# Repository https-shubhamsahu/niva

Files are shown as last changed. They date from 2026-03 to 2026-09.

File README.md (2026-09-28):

# Niva

**Every step, understood.**

Niva is an explainable gait-analytics platform for a smart insole. Plantar pressure, impact, and IMU telemetry are acquired on an ESP32, streamed to software, then scored with explicit biomechanics rules rather than a black-box model.

This repository is a monorepo for the three implemented Niva applications.

## Architecture

```text
Smart Insole (FSR + piezo + MPU6050)
    ↓
ESP32 firmware  (niva arduino)
    ↓
BLE is not implemented. Live transport is USB Serial and Wi-Fi WebSocket.
    ↓
Web dashboard / optional WS relay  (niva web)
    ↓
Clinician / analytics UI

Flutter app  (niva flutter)
    ↓
Patient/user-facing mobile experience (same JSON telemetry protocol)
```

What is actually in the code:

- Firmware reads four FSR channels, a piezoelectric channel, and an MPU6050 IMU (in the active sketch).
- Telemetry is JSON over WebSocket (`:81`) and CSV over USB Serial at 115200 baud.
- The web app is a React + Vite clinician/research dashboard with IndexedDB storage.
- The Flutter app is a native rebuild of that dashboard for mobile, using Hive instead of IndexedDB.
- EMA filtering and gait-phase logic live in the software biomechanics engines, not as a separate firmware filter stage.
- The implemented IMU is **MPU6050**. This repo does not contain BMI270 firmware.

## Repository structure

```text
Niva/
├── niva flutter/     Mobile application (Flutter)
├── niva arduino/     ESP32 / Arduino firmware
├── niva web/         Clinician dashboard, Vite app, and WS relay
├── hardware/         Wearable hardware prototype: CAD, KiCad, renders (engineering prototype)
├── docs/brand/       Logo source assets
├── README.md
└── .github/          GitHub Pages deploy workflow
```

| Directory | Responsibility |
|---|---|
| `niva flutter/` | Patient/user-facing Flutter app: dashboard, device pairing over WebSocket, insights, trends, CSV export |
| `niva arduino/` | ESP32 firmware: ADC acquisition, calibration, IMU, telemetry, Wi-Fi / WebSocket |
| `niva web/` | Clinician dashboard, biomechanics visualization, dataset export/upload, optional WebSocket relay |
| `hardware/` | Rev C.1 wearable prototype: printable FreeCAD pod enclosure and charging dock; KiCad 9 pod (routed, DRC-clean), cartridge strip, dock and insole sensing flex; verification plan; Blender scenes. Start at `hardware/outputs/NIVA-3D-engineering-prototype/README.md`. Not reviewed or released for fabrication. |

## Development prerequisites

Install only what you need for the component you are running:

- **Web:** Node.js 22+ and npm
- **Flutter:** Flutter SDK (Dart 3.3+)
- **Firmware:** Arduino IDE (or compatible ESP32 toolchain) with ESP32 board support

## How to run each component

### Web dashboard (`niva web`)

```bash
cd "niva web"
npm install
# if peer dependency conflicts appear:
npm install --legacy-peer-deps
npm run dev
```

Other supported scripts:

```bash
npm run build
npm run preview
npm run lint
```

Optional environment file: create `niva web/.env.local`

```bash
VITE_ESP32_WS_URL=ws://<esp32-ip>:81
VITE_ESP32_WS_RELAY_URL=wss://<your-relay-domain>/ws
VITE_ESP32_WS_RELAY_TARGET_KEY=target
VITE_DATASET_UPLOAD_URL=https://your-api.example.com/upload
VITE_DATASET_UPLOAD_TOKEN=your_optional_bearer_token
```

Optional local WebSocket relay (needed when a HTTPS dashboard must reach a `ws://` ESP32):

```bash
cd "niva web/relay"
npm install
npm start
```

### Flutter app (`niva flutter`)

```bash
cd "niva flutter"
flutter pub get
flutter analyze
flutter test
flutter run
```

ESP32 endpoint, relay URL, and upload URL are runtime settings on the Device tab (not build-time env files).

### Firmware (`niva arduino`)

Open one of these sketches in Arduino IDE, install the libraries listed in `niva arduino/README.md`, select an ESP32 board, and upload:

- **Active hardware sketch:** `niva arduino/niva_hardware/niva_hardware.ino`
- **Simpler hardcoded-WiFi sketch:** `niva arduino/esp32_gaitguard_wifi_manager/esp32_gaitguard_wifi_manager.ino`

Serial Monitor baud rate: **115200**.

## Hardware / firmware overview

Implemented on ESP32:

- FSR heel / inner / outer / toe on ADC pins 32, 33, 34, 35
- Piezoelectric heel disc on pin 36
- MPU6050 on I2C (SDA 21, SCL 22) in the active `niva_hardware` sketch
- Optional SH1106 OLED on the same I2C bus (address 0x3C)
- Oversampled ADC reads and zero-load tare calibration (NVS-persisted in the active sketch)
- WebSocket telemetry on port 81, USB CSV telemetry on Serial

The simpler `esp32_gaitguard_wifi_manager` sketch uses hardcoded Wi-Fi credentials and does not drive the IMU or OLED.

## Software overview

- **Web:** React 19, TypeScript, Vite, Tailwind, Recharts, IndexedDB
- **Flutter:** Flutter, Riverpod, Hive, `web_socket_channel`, `fl_chart`
- **Relay:** Node.js + `ws`
- **Deploy:** GitHub Pages via `.github/workflows/deploy-pages.yml` (builds `niva web`)

There is no application server or database in this repository. Dataset persistence is browser-local (IndexedDB) or on-device (Hive). CSV upload to an external research API is optional.

## Documentation

| Location | Contents |
|---|---|
| `niva flutter/README.md` | Flutter setup, architecture, and run commands |
| `niva arduino/README.md` | Firmware sketches, pin map, libraries |
| `niva web/README.md` | Dashboard setup, telemetry formats, Pages deploy |
| `niva web/JUDGES_WALKTHROUGH.md` | Algorithm and data walkthrough |
| `niva flutter/DESIGN.md` | Flutter visual/design notes |
| `niva flutter/BACKEND_LOGIC.md` | Data contract and storage |
| `docs/brand/` | Logo source assets |

This prototype is an engineering / research screening tool. It is not a medical diagnosis device.

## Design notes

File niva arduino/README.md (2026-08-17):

# Niva Arduino / ESP32 firmware

Embedded firmware for the Niva smart insole. This directory contains the ESP32 sketches that acquire FSR, piezo, and IMU data and stream telemetry to the Flutter app and web dashboard.

## Technology stack

- ESP32 + Arduino core
- WebSockets (Markus Sattler)
- WiFiManager (tzapu) in the active sketch
- U8g2 (olikraus) for the SH1106 OLED in the active sketch
- MPU6050 over raw I2C (address `0x68`) in the active sketch

There is no PlatformIO `platformio.ini` in this repository. Flash with Arduino IDE (or another Arduino-compatible ESP32 toolchain).

## Sketches

### Active: `niva_hardware/niva_hardware.ino`

This is the complete hardware sketch currently used on the insole:

- WiFiManager captive portal (`NIVA-GaitGuard-AP`)
- MPU6050 pitch / roll / accZ
- SH1106 128x64 OLED status display on the shared I2C bus
- 16x ADC oversampling
- Zero-load tare calibration with NVS persistence
- mDNS names `niva.local` / `gaitguard.local`
- WebSocket JSON on port 81 and USB CSV on Serial

Required libraries:

- WiFiManager by tzapu
- WebSockets by Markus Sattler
- U8g2 by olikraus

### Simpler variant: `esp32_gaitguard_wifi_manager/esp32_gaitguard_wifi_manager.ino`

Earlier GitHub sketch kept because it is still a valid, smaller firmware:

- Hardcoded SSID / password (`YOUR_HOTSPOT_NAME` / `YOUR_HOTSPOT_PASSWORD`)
- Zero-load calibration (40 samples, not stored in NVS)
- WebSocket JSON + USB CSV
- `pitch` / `roll` / `accZ` are sent as `0.0` (no IMU)

Required libraries:

- WebSockets by Markus Sattler

## Pin map (both sketches)

| Signal | GPIO |
|---|---|
| FSR heel | 32 |
| FSR inner | 33 |
| FSR outer | 34 |
| FSR toe | 35 |
| Piezo | 36 |
| I2C SDA (MPU6050 + OLED) | 21 |
| I2C SCL | 22 |
| Status LED | 2 |

## Telemetry

JSON over WebSocket (`ws://<esp32-ip>:81`):

```json
{"heel":42.00,"inner":68.00,"outer":31.00,"toe":27.00,"piezo":176.00,"pitch":-2.40,"roll":1.30,"accZ":9.72}
```

USB Serial CSV at 115200 baud:

```text
H,I,O,T,Piezo,Pitch,Roll,AccZ
```

Gait-phase classification and EMA smoothing are applied in `niva web` and `niva flutter`, not in these sketches.

## Setup / flash

1. Install Arduino IDE and ESP32 board support.
2. Install the libraries listed for the sketch you are flashing.
3. For the simpler sketch, edit `WIFI_SSID` and `WIFI_PASS` before upload.
4. Select your ESP32 board and port.
5. Open the `.ino` and upload.
6. Open Serial Monitor at **115200** baud and note the printed IP address.
7. Point the Flutter Device tab or the web Settings page at `ws://<ESP32_IP>:81`.

Runtime tare on the active sketch: send `calibrate` or `tare` over WebSocket or Serial.

## Connection to other Niva components

- `niva flutter` connects over WebSocket using the same JSON packet.
- `niva web` connects over WebSocket or USB Web Serial using the same JSON/CSV packet.
- `niva web/relay` can bridge `wss://` (HTTPS GitHub Pages) to the ESP32 `ws://` endpoint.

## Implementation notes

- IMU in firmware is **MPU6050**, not BMI270.
- Production ideas such as ESP32-C3, FPC insole, or screen-printed layers are not implemented in these sketches.
- BLE is not implemented in firmware.

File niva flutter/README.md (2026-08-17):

# Niva Flutter

Patient/user-facing mobile application for Niva (GaitGuard Nexus). This is a native Flutter rebuild of the web dashboard: Apple Health-inspired cards and activity rings, a procedurally drawn plantar pressure map, and the same explainable biomechanics engine.

It is not a WebView wrapper. It speaks the same ESP32 JSON-over-WebSocket protocol as `niva web`.

## Technology stack

- Flutter / Dart 3.3+
- Riverpod
- Hive + `shared_preferences`
- `web_socket_channel`
- `fl_chart`, `google_fonts`, `share_plus`, `http`

Platform folders already in this project: `android/`, `ios/`, `windows/`, `web/`.

## Directory structure

```text
lib/
  core/
    models/            Packet and metric types
    engine/            BiomechanicsEngine + SimulationEngine
    connectivity/      Esp32SocketService (WebSocket + reconnect)
    data/              Hive dataset store, settings, optional CSV upload
    providers/         TelemetryController is the source of truth
  features/
    dashboard/         Today: rings, foot map, live metrics
    trends/            Cadence / stability / impact charts
    insights/          Clinical summary + AI coach card
    device/            Connection, session metadata, export/upload
    shell/             Bottom tab shell
  theme/
  shared/widgets/
test/
  biomechanics_engine_test.dart
assets/
  images/feet.png
  icon/
```

## Setup

```bash
cd "niva flutter"
flutter pub get
flutter analyze
flutter test
flutter run
```

Android already enables `INTERNET` and `usesCleartextTraffic` so `ws://` ESP32 endpoints on the LAN can connect. iOS still needs a local-network usage description if you ship to a device (see `ios/Runner/Info.plist`).

## Configuration

There is no `.env` file. WebSocket URL, optional relay URL, session/trial IDs, and upload endpoint are runtime settings on the Device tab, persisted with `shared_preferences`.

## Connection to other Niva components

- Firmware: `niva arduino/niva_hardware/niva_hardware.ino` (active) or the simpler `esp32_gaitguard_wifi_manager` sketch. Packet shape is the same.
- Web: `niva web` is the clinician dashboard with USB Serial plus extra visualization pages that were not ported here (3D foot views, clinician PDF).
- BLE / USB-OTG are not implemented in this app. See `BETTERMENTS.md` and `CONNECTIVITY_PLAN.md`.

## Additional docs in this folder

- `DESIGN.md` — visual language
- `BACKEND_LOGIC.md` — data contract and storage
- `SIMULATION_LOGIC.md` — disease-mode simulator
- `BETTERMENTS.md` — follow-up ideas (BLE, HealthKit, etc.)

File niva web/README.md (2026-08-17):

# Niva web

Clinician / research dashboard for Niva (GaitGuard Nexus): live ESP32 telemetry, explainable gait analytics, IndexedDB datasets, and GitHub Pages deployment. The optional WebSocket relay lives in `relay/`.

# GaitGuard Nexus (NIVA)

<p align="center">
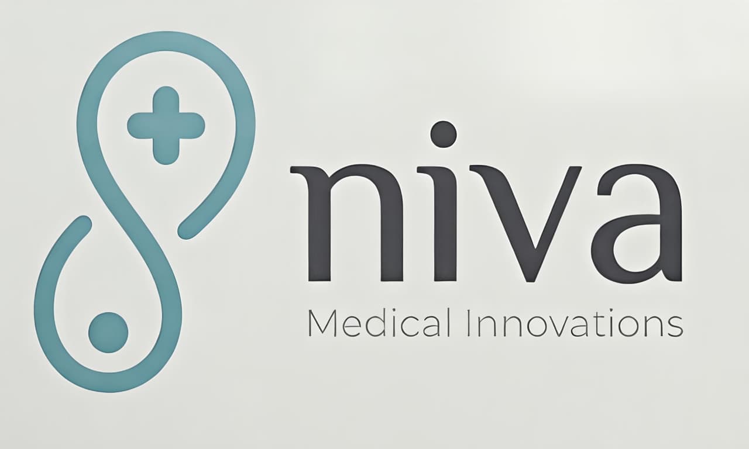
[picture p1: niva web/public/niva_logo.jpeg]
NIVA Logo
  
</p>

<p align="center">
  
  
  
  
</p>

Deterministic, explainable gait analytics platform for ESP32 smart insole telemetry.

This project focuses on transparent biomechanics logic rather than black-box prediction. Every score and alert can be traced to explicit sensor rules.

## Tech Stack

| Layer | Technology |
|---|---|
| Frontend | React, TypeScript, Vite |
| Hardware link | Web Serial (USB) + WebSocket (WiFi) |
| Storage | IndexedDB (browser-local dataset store) |
| Firmware | ESP32 (Arduino, WiFiManager + WebSockets) |
| Deployment | GitHub Pages via GitHub Actions |

## What This Project Does

- Streams plantar + IMU telemetry from ESP32 over USB Serial and WiFi WebSocket.
- Runs a real-time biomechanics engine for gait phase, cadence, COP, stability, and anomaly detection.
- Stores samples locally in IndexedDB with disease/session/trial metadata.
- Exports datasets as CSV and supports one-click backend upload for research pipelines.
- Supports disease-mode simulation for demos and algorithm walkthroughs.

## Explainability First

This is an explainable rule-based system. Core decisions are derived from explicit thresholds and state transitions:

- Contact detection from total normalized plantar pressure.
- Heel-strike events from impact + heel-rise transition constraints.
- Gait phase classification using interpretable phase rules.
- Cadence from heel-strike intervals.
- Stability from pitch/roll sway and impact penalties.
- Risk flags from sustained pressure and kinematic instability conditions.

Primary implementation file:

- src/utils/biomechanicsEngine.ts

## Data Pipeline

End-to-end flow:

ESP32 packet -> transport parsing -> biomechanics engine -> dashboard state -> dataset store -> CSV/export/upload

Coordinator file:

- src/pages/MainDashboard.tsx

## Architecture Diagram

<p align="center">
  GaitGuard Nexus Architecture Diagram
</p>

## Supported Input Formats

### USB Serial (CSV)

Expected line format:

```text
H,I,O,T,Piezo,Pitch,Roll,AccZ
```

Example:

```text
45,70,25,20,160,-2.1,1.4,9.78
```

### WiFi WebSocket (JSON)

Example payload:

```json
{"heel":42,"inner":68,"outer":31,"toe":27,"pitch":-2.4,"roll":1.3,"piezo":176,"accZ":9.72}
```

## Dataset Schema

Samples are persisted in browser IndexedDB.

- Database: gaitguard-nexus-datasets
- Store: esp32_samples

Per sample fields:

- timestampMs
- source (usb | ws | sim)
- sessionId
- trialId
- diseaseLabel (Unknown | Normal | Parkinson | Stroke | Neuropathy | Foot Drop | Ataxia)
- mode (live | simulation)
- heel
- inner
- outer
- toe
- impact
- pitch
- roll
- accZ

Disease labeling behavior:

- Live USB/WiFi packets use operator-selected disease label.
- Simulation packets auto-tag from active simulation mode.

## Backend Upload Contract

One-click upload sends multipart form-data with:

- file (CSV)
- sampleCount
- generatedAt
- datasetType (esp32-biomechanics)
- sessionId
- trialId
- diseaseLabel

Upload helper:

- src/utils/researchUpload.ts

## Quick Start

1. Install dependencies:

```bash
npm install
```

2. If peer dependency conflicts appear, use:

```bash
npm install --legacy-peer-deps
```

3. Start development server:

```bash
npm run dev
```

4. Open the app URL shown by Vite.

## Environment Variables

Create `.env.local` in this `niva web` directory if needed:

```bash
VITE_ESP32_WS_URL=ws://<esp32-ip>:81
VITE_ESP32_WS_RELAY_URL=wss://<your-relay-domain>/ws
VITE_ESP32_WS_RELAY_TARGET_KEY=target
VITE_DATASET_UPLOAD_URL=https://your-api.example.com/upload
VITE_DATASET_UPLOAD_TOKEN=your_optional_bearer_token
```

## ESP32 on Any Device (WiFi and Hotspot)

Use Settings -> ESP32 WebSocket Raw Stream to set endpoint at runtime.

Examples:

- `ws://192.168.4.1:81` (ESP32 AP mode)
- `ws://<hotspot-assigned-esp32-ip>:81`
- `wss://<your-secure-relay-domain>/ws` (recommended for deployed HTTPS pages)

Important browser rule:

- GitHub Pages runs on HTTPS.
- Browsers block `ws://` from HTTPS pages (mixed-content restriction).
- For deployed usage on any device, configure `VITE_ESP32_WS_RELAY_URL` (wss) so the app automatically switches to relay mode.
- If relay is not configured, open the app locally over HTTP for direct `ws://` testing.

Automatic seamless fallback:

- App attempts direct mode when allowed.
- On HTTPS + `ws://` endpoint, app auto-routes through relay when `VITE_ESP32_WS_RELAY_URL` is set.
- Relay query parameter name defaults to `target`, configurable via `VITE_ESP32_WS_RELAY_TARGET_KEY`.

Sharing endpoint to another device:

- Use `Copy Share Link` in Settings.
- The generated URL includes `?esp32ws=<endpoint>` and auto-applies endpoint on open.

## Beginner WiFi Setup for ESP32

This section is for first-time users with no networking background.

Ready-to-flash firmware lives in `niva arduino/`:

- Active hardware sketch: `niva arduino/niva_hardware/niva_hardware.ino` (WiFiManager, MPU6050, OLED)
- Simpler hardcoded-WiFi sketch: `niva arduino/esp32_gaitguard_wifi_manager/esp32_gaitguard_wifi_manager.ino`

See `niva arduino/README.md` for libraries and pin map.

### What you are configuring

Your ESP32 needs to do two things:

1. Join a WiFi network (home WiFi or phone hotspot).
2. Expose a WebSocket stream so the dashboard can read live packets.

### Method 1: Hardcode hotspot or WiFi in firmware (easiest)

Use this when starting out.

```cpp
#include <WiFi.h>
#include <WebSocketsServer.h>

const char* ssid = "ShubhamHotspot";
const char* password = "12345678";

WebSocketsServer wsServer(81);

void setup() {
  Serial.begin(115200);

  WiFi.begin(ssid, password);
  Serial.print("Connecting to WiFi");
  while (WiFi.status() != WL_CONNECTED) {
    delay(500);
    Serial.print('.');
  }

  Serial.println("\nWiFi Connected");
  Serial.print("ESP32 IP: ");
  Serial.println(WiFi.localIP());

  wsServer.begin();
}

void loop() {
  wsServer.loop();

  const String packet =
    "{\"heel\":0,\"inner\":0,\"outer\":0,\"toe\":0,\"pitch\":0,\"roll\":0,\"piezo\":0,\"accZ\":0}";

  wsServer.broadcastTXT(packet);
  delay(100);
}
```

After upload, open Serial Monitor. You should see:

- `WiFi Connected`
- `ESP32 IP: 10.x.x.x` or `192.168.x.x`

Then in app Settings:

- Connection Endpoint: `ws://<ESP32_IP>:81/`

If using deployed HTTPS app, also set Relay Endpoint.

### Method 2: WiFiManager (pro move)

If you do not want to hardcode WiFi every time:

- ESP32 creates its own setup WiFi.
- You connect once, enter credentials, and ESP32 saves them.

```cpp
#include <WiFi.h>
#include <WiFiManager.h>

WiFiManager wm;

void setup() {
  Serial.begin(115200);

  bool connected = wm.autoConnect("ESP32_Setup");
  if (!connected) {
    Serial.println("Failed to connect");
    return;
  }

  Serial.println("WiFi Connected");
  Serial.print("ESP32 IP: ");
  Serial.println(WiFi.localIP());
}

void loop() {}
```

How it works:

1. ESP32 starts temporary AP: `ESP32_Setup`.
2. Connect your phone to it.
3. Open `192.168.4.1` in browser.
4. Enter hotspot SSID/password.
5. ESP32 saves and reconnects automatically next boot.

### Common mistakes (do not ignore)

- Wrong hotspot name/password.
- WiFi names are case-sensitive (`ShubhamHotspot` is not `shubhamhotspot`).
- Weak hotspot signal (keep phone close to ESP32).
- 5 GHz hotspot only (ESP32 needs 2.4 GHz).
- Forgot to reboot ESP32 after changing WiFi.

### Pro tips

- Always print IP after connect:

```cpp
Serial.println(WiFi.localIP());
```

- Add LED indicator for connected/disconnected state.
- Use WiFiManager for real deployments with changing hotspots.
- Add auto-reconnect logic in `loop()`.

### Reality check

ESP32 does not behave like a phone that auto-discovers everything.

You must provide:

- WiFi network name
- WiFi password

Or implement logic (WiFiManager/fallback) that collects and stores this for you.

### Switching to another phone hotspot

When you change hotspot, ESP32 usually gets a new IP.

Do this every time:

1. Connect ESP32 and your relay laptop to the new hotspot.
2. Reboot ESP32.
3. Read new IP from Serial Monitor.
4. Update app Connection Endpoint to `ws://<new_ip>:81/`.
5. Keep same relay URL if still active, otherwise generate a new tunnel URL.

### Connection pitfalls in this project

- Relay URL expired (quick tunnel links are temporary).
- ESP32 got a new hotspot IP and app still points to old IP.

### Make it less fragile (recommended)

For better real-world behavior, implement:

- Auto reconnect when `WiFi.status() != WL_CONNECTED`.
- Fallback list of known SSIDs.
- Periodic `Serial.println(WiFi.localIP())` after reconnect.
- Status LED for connected/disconnected state.

## Main Routes

- /main: live telemetry dashboard + simulation + dataset controls
- /settings: Nexus console, hardware matrix, raw WebSocket monitor
- /insights: clinical insights views
- /trends: trend analytics

Router definition:

- src/App.tsx

## Key Files

- src/pages/MainDashboard.tsx: transport integration, engine binding, dataset actions
- src/utils/biomechanicsEngine.ts: explainable gait algorithms
- src/utils/esp32Telemetry.ts: USB CSV parser
- src/hooks/useSensorData.ts: WebSocket hook with reconnect
- src/utils/telemetryDatasetStore.ts: IndexedDB and CSV export
- src/utils/researchUpload.ts: backend upload utility
- src/utils/simulationEngine.ts: synthetic disease-mode frame generator
- JUDGES_WALKTHROUGH.md: algorithm and data presentation script

## Scripts

- npm run dev: start local dev server
- npm run build: type-check and production build
- npm run preview: preview production build
- npm run lint: run ESLint

## WebSocket relay

`relay/` is a small Node.js proxy used when a HTTPS dashboard (GitHub Pages) must reach an ESP32 `ws://` endpoint.

```bash
cd relay
npm install
npm start
```

Default listen URL: `http://localhost:8787` with WebSocket path `/ws`. Do not commit `node_modules` or cloudflared log files.

## Deploy to GitHub Pages

This repo is configured for Pages deployment through GitHub Actions.

Workflow file (repository root):

- `.github/workflows/deploy-pages.yml` (builds this `niva web` directory)

How it works:

1. On push to main (or manual run), GitHub Actions installs dependencies and builds the Vite app.
2. Build base path is set automatically to /<repo>/ in CI using GITHUB_REPOSITORY.
3. The workflow copies dist/index.html to dist/404.html for SPA route fallback.
4. The generated dist artifact is deployed to GitHub Pages.

One-time GitHub setup:

1. Open repository Settings -> Pages.
2. Under Build and deployment, set Source to GitHub Actions.
3. Push your latest code to main.
4. Wait for Deploy to GitHub Pages workflow to complete.

Expected URL format:

- https://<your-username>.github.io/<your-repo>/

### Configure Relay Variables for Pages Build

For seamless ESP32 connectivity on deployed HTTPS pages, set repository variables:

1. Open GitHub repository Settings -> Secrets and variables -> Actions -> Variables.
2. Add variable VITE_ESP32_WS_RELAY_URL with your secure relay endpoint (example: wss://relay.yourdomain.com/ws).
3. Optional: add variable VITE_ESP32_WS_RELAY_TARGET_KEY if your relay expects a key other than target.
4. Optional: add variable VITE_ESP32_WS_URL for your default direct endpoint.
5. Push a new commit to main (or re-run the deploy workflow) so Vite rebuilds with updated variables.

This workflow reads these variables in:

- .github/workflows/deploy-pages.yml

## Troubleshooting

- Web Serial requires Chromium-based browser and localhost/https context.
- Ensure ESP32 serial baud rate is 115200.
- If no live data appears, check cable quality and COM port permissions.
- If WiFi stream fails, verify VITE_ESP32_WS_URL and ESP32 WebSocket server port.

## Research and Clinical Notes

This repository currently provides an engineering prototype for explainable screening support and data collection. It is not a medical diagnosis device.

For judging and deep algorithm mapping, see:

- JUDGES_WALKTHROUGH.md

## Contributing

Fork the repository, create a feature branch, and open a pull request. Please keep new gait-state logic explainable (explicit thresholds/rules) rather than introducing opaque ML models, per this project's core design principle.

## License

No license file is currently present in this repository.

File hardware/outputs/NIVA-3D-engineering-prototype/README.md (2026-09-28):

# NIVA 3D engineering prototype — Revision C.1

Bilateral gait-sensing research/screening kit with four parts:

- **Insole:** a five-region force insole with a heel PVDF film and a protected flat tail.
- **Pod:** worn on the lower shin (ESP32-C3, MCP3208, LSM6DSO32, removable battery cartridge, one button, one light) and controlled offline from a phone over Bluetooth.
- **Cartridge:** a removable battery cartridge.
- **Dock:** a desk dock that charges bare cartridges.

> **Status: engineering prototype for fit, handling and bench work. Not a released medical device. Not released for fabrication.**
> - Every KiCad board is routed and passes KiCad ERC and DRC. That is an automated check, **not a design review**.
> - Gerbers exist only in `fab-REVIEW-ONLY-NOT-RELEASED/` folders, each with a list of open blockers.
> - Nothing has been built, powered or measured. Nothing here establishes clinical performance.
> - The sensing concept does **not** measure medial knee contact force.
> - Sealing, skin contact and cleaning are **unverified**: see `VERIFICATION-PLAN.md`.

## What changed in Rev C.1 (this update)

| Open item in Rev C | Rev C.1 resolution | Still open |
|---|---|---|
| Pod PCB unrouted. Freerouting stalled at about 40 open connections, no Gerbers. | GND fan-out first: every GND pad gets its own via to the solid In1 plane. Signals are then autorouted, followed by pours and stitching. **0 DRC errors, 0 unconnected, parity clean.** Review-only Gerbers/drill/placement files. | Independent review, fab DFM, return-path and RF review |
| R33 = 220 Ω made every force reading depend on VEXC, so firmware had to normalise it. | The MCP3208 VREF is now VEXC, so readings are ratiometric in hardware and need **no firmware normalisation**. CH6 becomes a tail-fault monitor. | Bench confirmation |
| Dual clamp diodes not used (contradictory KiCad symbol). | One **BAV199** series pair (SOT-23) on a project symbol that states the data-sheet pinning (1 A1, 2 K2, 3 K1/A2). | Check the reel marking; the PDF host was unreachable, so the pinning comes from two search sources quoting the Nexperia data sheet |
| Battery cell not selected; 300 mAh fit unproven. | EEMB **LP502030** class (230 mAh min, 20.5 × 32 × 5.3 mm max, PCM + NTC). The cartridge is resized around its maximum size plus 8 % swell. **300 mAh does not fit and is not claimed.** | A purchased lot, swelling under cycling, and cell safety evidence |
| Cartridge electronics not designed. | `electronics/cartridge/`: interconnect strip PCB with a series polyfuse and gold dock pads. No active parts. The cell PCM is protection layer 1. | Polyfuse part number, pad wear |
| Charging dock not designed. | `electronics/dock/`: USB-C, MCP73831 at 100 mA, and a **hardware NTC window** (LM393 → PROG gate). `mechanical/` has a printable dock with a keyed well, tab ledge, snap latch, spring-pin holes and a light pipe. | Spring-pin part not selected; thresholds and termination unmeasured |
| Insole tail could not reach the big toe (A201 tails too short, hold H1). | `electronics/insole/`: an **integrated sensing flex** (R and L). Five printed shunt-mode electrodes and PVDF bond pads, with copper lanes to the heel tab. Only F.Cu and no parts underfoot. A 115 mm tail runs to a stiffened above-collar transition that carries the insert ID resistor. | FSR ink film selection and characterisation, fatigue, lamination |
| No sealing, skin-contact or cleaning claims. | Still **none claimed**. `VERIFICATION-PLAN.md` gives materials, test methods and proposed acceptance criteria. | Every test in that plan |
| Blender PCB close-up read too light green. | Root cause: KiCad 9's GLB writer stores sRGB colours as linear glTF factors. The import now linearises them, and the close-up lights no longer mirror into the glossy mask. | — |

## Contents

```
NIVA-3D-engineering-prototype/
├── README.md                          this file
├── VERIFICATION-PLAN.md               sealing / skin contact / cleaning (and dependent) tests - plan only, no claims
├── mechanical/
│   ├── NIVA-RevC-assembly.FCStd/.step pod assembly: groups Pod_R and Pod_L (left pod at x - 80 mm), incl. routed PCBA
│   ├── NIVA-dock-assembly.FCStd/.step dock assembly with dock PCBA and a seated cartridge
│   ├── STEP-parts/, STL-print-parts/  12 printable parts (01-09 pod, 10-12 dock); STLs in print orientation
│   ├── PRINT-AND-ASSEMBLY.md          materials, orientation, fasteners, clearances, pod/cartridge/dock assembly, open items
│   ├── geometry-validation.json, dock-geometry-validation.json     per-part solid/mesh checks
│   └── interference-report.json, dock-interference-report.json     pairwise interference + functional gaps
├── electronics/
│   ├── NIVA-pod.kicad_pro/.kicad_sch/.kicad_pcb + 2 sub-sheets     pod: 4-layer 34 x 48 mm, ROUTED
│   ├── ELECTRICAL-REVIEW.md           findings, ERC, pin/boot review, analog values, power, PCB, open items
│   ├── exports/                       pod schematic PDF/SVG, ERC, BOM, netlist; pcb/ DRC, assembly PDFs, PCBA STEP+GLB,
│   │                                  fab-REVIEW-ONLY-NOT-RELEASED/ (Gerber, drill, placement, STATUS.txt)
│   ├── cartridge/  NIVA-cartridge.*   interconnect strip (hand-routed) + exports/ (same structure)
│   ├── dock/       NIVA-dock.*        charging dock (autorouted) + exports/
│   ├── insole/     NIVA-insole-R.*, NIVA-insole-L.*   sensing flex, right/left medium + exports/
│   ├── 3dmodels/                      STEP models (KiCad library, Espressif, *_ENVELOPE stand-ins)
│   └── work-routing/                  Specctra DSN/SES + Freerouting logs (the sessions actually imported)
├── renders/                           11 captioned images: 01-07 Blender scenes, pcb_* KiCad raytraces; raw/, pcb-raw/ originals
└── blender/
    ├── NIVA-RevC-scenes.blend         editable Blender 4.5 file: 7 scenes + hidden library collections
    └── 01..07_*.glb                   glTF binary of each scene
```

## Opening the files

- **FreeCAD 1.1:** open `mechanical/NIVA-RevC-assembly.FCStd` or `NIVA-dock-assembly.FCStd`. Objects carry `Material`, `Kind` and `Note` properties. The models are solid assemblies generated by script, so change dimensions in `work/niva_layout.py` and re-run the generators.
- **KiCad 9:** open any `.kicad_pro`.
  - Project libraries resolve through `${KIPRJMOD}`; 3D models through `${KIPRJMOD}/3dmodels` (pod) or `${KIPRJMOD}/../3dmodels`.
  - The insole flex boards use negative y coordinates: the insole frame has the heel at y = 100 mm and the toe above it.
- **Blender 4.5:** open `blender/NIVA-RevC-scenes.blend`, which has scenes `01_Pod_Assembled` … `07_Insole_Flex`. The `LIB_*` collections hold the source meshes and GLBs (render-hidden).
- **Any glTF viewer:** `blender/*.glb` and `electronics/**/exports/pcb/*-PCBA.glb`.

## Boards at a glance

| Board | Size / layers | Routing | KiCad ERC / DRC (schematic parity on) |
|---|---|---|---|
| Pod | 34 × 48 × 1.0 mm, 4 layers (In1 = GND plane) | GND fan-out, then Freerouting signals, then pours; 547 segments, 126 vias | 0 errors, 1 reviewed warning / **0 errors, 0 unconnected**, 3 silk warnings (module outline at the antenna edge) |
| Cartridge strip | 3.4 × 30 × 0.8 mm, 2 layers | hand-routed | 0 / 0, 0 unconnected |
| Dock | 58 × 56 × 1.6 mm, 2 layers | Freerouting + GND pours | 0 / 0, 0 unconnected |
| Insole flex R, L | 0.12 mm polyimide; F.Cu only underfoot | generated paired lanes; B.Cu only at the above-collar transition | 0 / 0, 0 unconnected |

## Printing and assembly

See `mechanical/PRINT-AND-ASSEMBLY.md`. It covers:
- material and print orientation for all 12 printed parts;
- fasteners for the pod and dock;
- nominal clearances measured in CAD;
- pod, cartridge and dock assembly sequences;
- the list of unverified fits and safety mechanisms.

## Complete vs provisional

| Area | Complete in this package | Provisional / open |
|---|---|---|
| Pod enclosure | Rev C solids and printable STL/STEP for R and L; interference audit against the routed PCBA (only the intended spring preload overlaps) | Every 0.2 mm fit, sealing, latch and screw durability, skin contact, cleaning |
| Battery | Selected cell class; cartridge cup, lid, strip PCB, pads and windows; charge-only-when-removed concept | Purchased lot, swelling, lid welding, cell safety evidence |
| Dock | Schematic, routed PCB and printable enclosure; audit shows only the intended spring-pin compression | Spring-pin part, measured thresholds and termination, latch life |
| Schematic | Connected hierarchy, ratiometric ADC, reviewed values, ERC-clean | Bench validation of the analog front end, datasheet re-checks listed in the review |
| Pod PCB | Routed, DRC-clean, review-only fab data | Independent review, fab DFM, RF and return-path review |
| Insole | Sensing flex R/L (schematic, routed layout, review-only fab data); visual insert from the 1:1 fit template | FSR film, lamination, fatigue, sweat ingress, other sizes (no automatic grading) |
| Renders | 7 Blender scenes + 4 KiCad raytraces, captioned with status | Soft goods (strap, tail) are parametric bands, not CAD parts |

## Regenerating

Everything is script-generated. From `hardware/work/` (paths below are the Linux build used for this package: KiCad 9.0.9 in Docker via a `kicad9` wrapper, FreeCAD 1.1.3, `bpy` 4.5, Freerouting 2.1.0 via `niva-route`, which is Freerouting headless on `work-routing/<name>.dsn`):

```sh
python3 build_niva_schematic_revC.py            # pod schematic + project rules
python3 build_niva_power_schematics.py          # cartridge + dock schematics
python3 build_niva_insole_flex.py               # insole flex schematics, footprints, lane geometry (needs shapely)
# netlists: kicad-cli sch export netlist --format kicadsexpr -o <dir>/exports/<name>.net <name>.kicad_sch
kicad9 python3 build_niva_pcb.py place <pod|cartridge|dock|insole-R|insole-L>
niva-route NIVA-pod 100 900                     # (and NIVA-dock); cartridge and insoles are hand/generated
kicad9 python3 build_niva_pcb.py finalize pod "<status>" ../outputs/.../work-routing/NIVA-pod.ses
kicad9 python3 build_niva_pcb.py finalize cartridge "<status>" hand     # likewise insole-R / insole-L
python3 export_niva_electronics.py              # ERC, DRC, PDFs, BOMs, STEP/GLB, review-only fab data
./render_kicad_pcb.sh                           # KiCad raytraces of the pod
PYTHONPATH=/opt/freecad/lib /opt/freecad/bin/python build_niva_envelopes.py   # spring-pin envelope model
PYTHONPATH=/opt/freecad/lib /opt/freecad/bin/python build_niva_cad_revC.py    # pod enclosure + audit
PYTHONPATH=/opt/freecad/lib /opt/freecad/bin/python build_niva_dock_cad.py    # dock enclosure + audit
/opt/bpyenv/bin/python build_niva_scenes.py && python3 caption_renders.py
```

- **UUIDs:** the schematic generators use deterministic UUIDs, so re-running them keeps each schematic and PCB linked.
- **Autorouting:** Freerouting is not deterministic. The committed `.ses` files are the ones that were imported and DRC-checked; a new routing run must be re-checked.

## Sources and third-party assets

- **Engineering brief:** "Niva prototype blueprint: from bench insole to health-camp kit", draft v0.1 (`hardware/brief/engineering-brief.txt`). Its component choices were reviewed, not assumed validated. Its prices, literature figures and unpublished study results are not adopted here.
- **Rev A vector blueprints:** `outputs/niva-vector-blueprints/`. The 1:1 fit template supplies the insole outline, the sensor-region centres and the heel tab used by the flex and the renders.
- **Espressif KiCad libraries** (ESP32-C3-MINI-1 symbol, footprint and STEP model): github.com/espressif/kicad-libraries, commit `dd76561`. CC-BY-SA 4.0 with the design-use exception. The symbol was converted to KiCad 9 format; the footprint and model are unmodified.
- **KiCad 9 libraries:** symbols and footprints from KiCad 9.0.9. 3D models from gitlab.com/kicad/libraries/kicad-packages3D, tag 9.0.0 (KMR2 from `master`). CC-BY-SA 4.0 with the design-use exception.
- **Simplified envelopes (not supplier models; orange in the renders):**
  - `TDFN-8-2x2mm_ENVELOPE.step` (MAX17048);
  - `NIVA_SpringContact_1x04_ENVELOPE.step` (pod J2);
  - `NIVA_SpringPin_1x03_ENVELOPE.step` (dock J2);
  - the cell, drawn at its published maximum size.
- **Component data used in Rev C.1** (from web search, because manufacturer sites were blocked from the build environment):
  - MCP3208 VREF range 0.25 V–VDD and VREF current (Microchip DS21298);
  - MCP73831 PROG behaviour and I_REG = 1000 V / R_PROG (Microchip);
  - LM393 input common-mode behaviour (TI);
  - EEMB LP502030 size and capacity (EEMB listing);
  - BAV199 pinning and leakage (Nexperia data sheet, as quoted in search results).

  Confirm each against the current PDF before any release.
- **Tools:**
  - FreeCAD 1.1.3.
  - KiCad 9.0.9 (Docker `kicad/kicad:9.0`).
  - Blender 4.5.14 LTS (`bpy`).
  - Freerouting 2.1.0.
  - shapely 2.1 (flex geometry).
  - DejaVu Sans font (CAD lettering).

## Checks actually completed

- **KiCad CLI, every board:**
  - ERC with all severities;
  - DRC with schematic parity;
  - netlist, BOM, PDF, STEP and GLB exports;
  - review-only Gerber, drill and placement exports;
  - raytraced renders of the pod.
- **FreeCAD:**
  - Every printable part is one valid solid with a closed, manifold mesh.
  - Pairwise interference audits cover the right pod, including the routed PCBA and the cartridge internals, and the dock with a seated cartridge.
  - The only intersections are the intended spring-contact and spring-pin compressions.
- **Insole flex:** the lane corridors stay at least 1 mm inside the 1:1 insole outline, except where the lanes intentionally cross the edge into the heel tab. This is checked by the generator.
- **Blender:** all scenes were rendered and visually inspected. The KiCad GLB colour error was diagnosed and fixed at the import.
- **Not done:**
  - any physical print or electrical build;
  - any measurement;
  - RF test;
  - sealing, skin, pressure or cleaning tests;
  - FSR characterisation;
  - independent design review.

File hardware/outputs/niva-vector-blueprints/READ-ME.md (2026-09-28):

# NIVA — vector industrial-design blueprints

Revision A · 28 September 2026

This package translates the user-supplied Claude engineering brief into a dimensioned industrial-design concept. It preserves the bilateral passive insole, shin IMU, protected interconnect, detachable battery, offline phone workflow and bench-first development sequence. NIVA follows the spelling in the supplied engineering document.

## Files

- **NIVA-vector-blueprints-Rev-A.pdf:** six A3 landscape sheets, entirely vector linework and text.
- **01-shin-pod.svg:** front, side, rear and exploded section, proposed envelope and assembly stack.
- **02-insole-sensor-stack.svg:** anatomical sensing map, soft layer section, seal and routing intent.
- **03-footwear-integration.svg:** chappal, sandal and shoe attachment diagrams; barefoot/gumboot fallback.
- **04-battery-and-side-keys.svg:** cartridge removal, charging exclusion, battery envelope and connector keys.
- **05-electronics-and-packaging.svg:** signal architecture, preliminary connector functions and board zoning.
- **06-camp-kit-and-roadmap.svg:** case plan, service parts and development gates.
- **07-full-size-fit-template.svg:** supplementary left/right medium outline at 1:1 on A3.
- **index.html:** local gallery for viewing the drawings. Open alongside the SVG files.

SVG shapes and text remain editable in vector-design applications. These are 2D drawings, not STEP solids, native mechanical CAD, schematics, Gerbers, laser-cut files or mould tooling. Fonts use Helvetica/Arial fallbacks. PDF pages preserve vector content and can be zoomed without raster loss.

## Reading and printing

All dimensions are millimetres. **P** denotes a proposed design target; **V** denotes a limited component dimension checked against the named source. No general manufacturing tolerance is assigned. Views show scales individually; conceptual sections and mechanisms marked NTS must not be measured from the page.

Print A3 at 100%, without “fit to page.” The supplemental outline includes a 100 mm check bar. It is for geometry and fitting discussions only; do not cut production sensor sheets from it. The anatomical positions are explicit design seeds, not measurements from North East Indian users. Small and large sizes must be developed using measured feet rather than uniformly scaling the medium sensing map.

## Deliberate changes and open decisions

1. **Pod envelope:** the original 48 × 34 × 13 mm visual target is replaced by a provisional 60 × 42 × 20 mm custom-PCB target. This reserves space for a rear battery bay and serviceable enclosure; it does not prove component fit. The breakout-board prototype needs its own enclosure sized after actual parts are selected and measured.

2. **Tail reach — hold H1:** the standard A201 is approximately 190.5 mm overall, not 191 mm of usable tail beyond its sensing element. In the proposed medium template the big-toe region is over 200 mm from the heel even before margin routing and an above-collar junction. Stock A201 parts cannot implement the illustrated common-heel topology as assumed in the supplied brief. The dashed paths express design intent. Use stock sensors for bench experiments; a wearable requires a supplier-approved longer/custom flexible sensing assembly or a separately validated routing redesign. No rigid extension joints are permitted underfoot. Custom force sensors are an available supplier category, but no specific custom part has been sourced or qualified.

3. **Rigid junction placement:** move sensor terminations and the insole ID resistor into the protected assembly above the shoe collar, rather than placing a resistor or hard sensor pins inside the insole. Longer passive tails and their resulting noise remain an unresolved development item. The sensor, tail and encoded connector are a paired service assembly.

4. **Battery:** cartridge envelope 28 × 34 × 8 mm is provisional, including protection electronics, recessed contacts and shell. The proposed internal cell envelope is not a sourced cell. The brief's 300 mAh capacity is therefore not guaranteed. Select the cell, allow for swelling and tolerances, and then revise the cartridge and pod together. Runtime is not claimed in these drawings.

5. **Charging exclusion:** the proposed cradle covers the cartridge release; the whole pod cannot enter the charger. This is an intended mechanical exclusion, not an established safety result. Rear access, latches, dock apertures, contacts and thermal faults require physical and electrical testing. Test foreseeable attempts to defeat the arrangement, not only the normal use sequence.

6. **Left/right:** distinct connector and cradle keys prevent crossed assembly. They cannot alone prevent a complete matched assembly being placed on the wrong leg. Retain an anatomical fitting check and an explicit side confirmation in the phone workflow.

7. **Analog electronics:** manufacturer A201 performance is specified with an op-amp circuit. The divider approach in the supplied brief remains a bench option rather than a validated equivalent. The drawing consequently reserves a force analog-front-end zone without freezing resistor values or the final drive topology. Review ADC settling, boot-strapping pins, battery sag/regulator dropout, simultaneous radio use and timing accuracy before schematic release.

8. **Insole construction:** the proposed skin is continuously sealed TPU-faced material; no exposed knit at edges. The 2.8 mm target depends on adhesive, recessed tails and the independent PVDF pocket. Active sensor diameter is not the full sensor footprint. Obtain actual supplier outlines before pocket cutting. No hard load-spreading puck is specified underfoot.

9. **Case:** a proposed 400 × 330 × 115 mm case accommodates the medium insert without folding it across sensors. The insert bay provides about 294 mm in length in this layout. Check the final largest size, oversoles, cable storage and lid depth before tray tooling.

## Sources and provenance

**User source:** “Niva prototype blueprint: from bench insole to health-camp kit,” Claude draft v0.1, dated 28 September 2026, supplied as pasted text. Its unpublished StepUP/R2 results, prices, literature accuracy figures and proposed electrical pin assignments have not been independently verified and are not adopted as proven performance in these drawings.

**S1 — Tekscan, FlexiForce A201:** [manufacturer product specifications](https://www.tekscan.com/products-solutions/force-sensors/a201). Checked 28 September 2026. The drawing uses the published 0.203 mm thickness, 0.375 in / 9.53 mm active diameter and 7.50 in / 190.5 mm standard overall length. The manufacturer recommends an op-amp readout and describes performance under that circuit condition.

**S1a — Tekscan, standard and custom force sensors:** [manufacturer sensor range](https://www.tekscan.com/force-sensors). Supports the availability of custom sensing development in general, not the availability or approval of the proposed long-tail assembly.

**S2 — Espressif, ESP32-C3-MINI-1 / MINI-1U datasheet v2.2:** [manufacturer datasheet](https://documentation.espressif.com/esp32-c3-mini-1_datasheet_en.pdf). Checked 28 September 2026. The module dimension used is 13.2 × 16.6 × 2.4 mm. The shaded RF zone is a reservation, not a validated antenna keepout or RF layout.

## What the engineering team should resolve next

1. Bench-select the force sensor and characterize the assembled soft stack.
2. Obtain full sensor/tail drawings and resolve H1 without hard plantar joints.
3. Select the battery and components; perform a full 3D tolerance and interference check.
4. Validate foot alignment, retention, collar pressure and local pressure distribution using fit models and a suitable test protocol.
5. Test the charging exclusion, cleaning durability, ingress, strain relief and side checks.
6. Only then release detailed CAD, schematic, PCB and manufacturing drawings.

The artwork intentionally does not assert a medical diagnosis, validated knee-load estimate, ingress rating, skin-contact certification, cleaning compatibility, runtime or production cost.

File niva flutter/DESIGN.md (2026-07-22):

# GaitGuard Nexus — UI/UX Design Reference

This documents the app's actual, current design system and screen-by-screen UI/UX as implemented in `lib/`. It reflects the real code, not aspirational design — see `BETTERMENTS.md` for proposed-but-not-built ideas and `CONNECTIVITY_PLAN.md` for the connectivity-specific implementation history.

## Design philosophy

The app is a from-scratch Flutter rebuild of a React/ESP32 gait-monitoring dashboard, redesigned around **Apple Health's visual language** rather than the original web app's indigo/slate theme. Three ideas drive every screen:

1. **Grouped, layered backgrounds.** A muted `systemGroupedBackground`-style page background with white (light) / near-black (dark) cards floating on top — never one flat page surface.
2. **A small set of vivid ring colors, reserved for headline metrics only.** Everything else stays muted (grays, brand indigo) so the three saturated colors stay meaningful at a glance instead of being diluted across the whole UI.
3. **Confident, heavy display type for hero numbers, dropping straight to quiet uppercase micro-labels for context.** No mid-weight type in between — a big stat is either the hero number or a label, never something in-between competing for attention.

Every score and flag in the app traces to an explicit, published threshold in `lib/core/engine/biomechanics_engine.dart` — there is no ML/black-box model. The UI is designed to make that explainability visible (e.g. the Insights screen's "Why These Alerts Fire" card spells out the exact thresholds).

## Design tokens (`lib/theme/app_theme.dart`)

### Color

| Token | Light | Dark | Used for |
|---|---|---|---|
| `stability` | `#FF375F` | same | Outer activity ring, Stability legend/value |
| `cadence` | `#9AE22B` | same | Middle activity ring, Cadence legend/value |
| `safety` | `#00E5FF` | same | Inner activity ring, Impact-safety legend/value |
| `warning` | `#FF9F0A` | same | Warning banners, moderate stability band |
| `danger` | `#FF453A` | same | Errors, disconnect button, unstable band, anomaly labels |
| `success` | `#32D74B` | same | Connected/live pulse dot |
| `brand` | `#415AEE` | same | Primary buttons, active tab, COP marker, segmented-toggle active state (carried over from the original GaitGuard Nexus branding — the one color that isn't Apple Health-native) |
| `background` | `#F2F2F7` | `#000000` | Scaffold background |
| `card` | `#FFFFFF` | `#1C1C1E` | `RoundedCard`, tab bar, all card surfaces |
| `label/secondary` | `#8E8E93` | `#98989F` | Micro-labels, secondary text, inactive tab icons |
| `divider` | `#E5E5EA` | `#2C2C2E` | Tab bar top border |

Ring/status colors are **identical in both themes** — only backgrounds, cards, and secondary text invert. This matches the real Dart source (`AppColors` doesn't branch these on brightness).

### Typography

Google Fonts **Inter**, five-step ramp, no mid-weights:

| Style | Size | Weight | Letter-spacing | Where |
|---|---|---|---|---|
| Display Large | 40 | 800 (Extra Bold) | -0.5 | Hero numbers (ring center value, "82") |
| Headline Medium | 22 | 800 | -0.3 | Screen titles ("GaitGuard Nexus", "Trends", "Health Insights", "Device") |
| Title Medium | 15 | 700 (Bold) | 0 | Metric values, legend values |
| Body Medium | 14 | 500 (Medium) | 0 | Paragraph copy, explanatory text |
| Label Small | 11 | 700 | 0.6 | Uppercase micro-labels, always the same secondary color |

### Motion (`AppMotion`)

- `springCurve` = `Curves.easeOutCubic` — the one curve used everywhere, standing in for a native spring feel.
- `medium` = 420ms — card-level transitions, chip toggles.
- `fast` = 220ms — small state flips (demo toggle, chip selection).
- Ring fills animate **independently per ring** via `TweenAnimationBuilder` (700ms, `easeOutCubic`) — updating one metric doesn't restart the others.
- The connection badge's pulse ring loops continuously (1400ms) behind the status dot whenever a live/simulated stream is flowing.
- The COP marker eases to its new position over 260ms (`easeOutCubic`) whenever a new sample arrives; a 12-point fading trail follows it.
- `RoundedCard` uses an `AnimatedContainer` (200ms) so radius/color changes never snap.

### Shape & spacing

- One card primitive everywhere: `RoundedCard` (`lib/shared/widgets/rounded_card.dart`), radius varies per context (18 for small metric tiles, 20–22 for compact cards, 26–28 for standard cards, 32 for the hero rings card) but the *shape language* — flat color, no border, no shadow — never varies.
- Standard screen padding: `20` horizontal, `12` top, `32` bottom.
- Standard inter-card gap: `16`.

## Navigation (`lib/features/shell/app_shell.dart`)

Bottom tab bar, 4 tabs, built on `IndexedStack` (not named routes) so all four screens stay mounted simultaneously — switching tabs never tears down the telemetry stream or resets scroll position:

| Tab | Icon | Screen |
|---|---|---|
| Today | `grid_view_rounded` | Dashboard |
| Trends | `trending_up_rounded` | Sparkline history |
| Health | `favorite_rounded` | Plain-English insights |
| Device | `settings_rounded` | Connection + data management |

Active tab: brand indigo icon+label. Inactive: secondary gray. Tab bar sits on a `card`-colored surface with a hairline top divider (0.6px), slightly translucent (92% opacity) so content can be glimpsed scrolling underneath.

## Screen 1 — Today (`dashboard_screen.dart`)

The flagship screen; everything reads from `TelemetryController` (Riverpod), never touches a socket or timer directly.

1. **Header** — app title (Headline Medium) + `ConnectionBadge`: a pulsing colored dot + uppercase label reading `LIVE TELEMETRY` / `SIMULATION RUNNING` / `NOT CONNECTED` depending on state.
2. **Connection error banner** (conditional) — only shown when a connection error exists *and* the app isn't simulating, so a stale error from a previous session doesn't obscure a working demo.
3. **Live/Simulation segmented toggle** — pill-shaped `SegmentedToggle`, slides between "LIVE SENSOR" and "SIMULATION" with a 260ms `AnimatedContainer`.
4. **Gait explanation card** (simulation mode only) — plain-English one-liner naming the active `GaitMode` and why it looks the way it does (e.g. "Low heel impact combined with increased stance duration suggests Parkinsonian shuffling gait").
5. **Activity rings card** — the signature element. Three concentric rings (`HealthRings`, hand-drawn with `CustomPainter`, no chart library), each sweeping clockwise from 12 o'clock: outer=Stability (red-pink), middle=Cadence (green), inner=Safety (cyan). Center shows the hero Stability number. A legend column to the right repeats each ring's color dot + label + live value.
6. **Metrics grid** — 2×3 grid of `MetricTile`s: Gait Phase, Steps, Stance/Swing ratio, Stability Band (color-coded green/orange/red), MLPI, Impact %.
7. **Plantar Pressure Map card** — see dedicated section below; this is the most recently redesigned part of the app.
8. **Anomaly card** (conditional) — only rendered when `anomalyFlags` is non-empty; red label + bulleted list.
9. **Disease selector** (simulation mode only) — chip row of all `GaitMode`s plus a "RUN DEMO"/"STOP DEMO" auto-cycle toggle that rotates through every mode every ~4s hands-free.
10. **Dataset strip** — small storage icon + running sample count + last save status, always visible at the bottom.

### Plantar Pressure Map (redesigned)

Replaced a procedurally-drawn single-foot outline with the real FSR reference diagram (`assets/images/feet.png`, sourced from the original web app), showing **both feet** side by side:

- **Header row**: "PLANTAR PRESSURE MAP" label, a **"12-BIT ADC" badge** (lavender/indigo pill — not decorative; the ESP32's ADC really is 12-bit, matching the `/4095` normalization in `biomechanics_engine.dart`), and a "COP" legend dot.
- **Four glow zones per foot** — Toe, 1st MT (medial forefoot), 5th MT (lateral forefoot), Heel — rendered as soft `RadialGradient` blurs in indigo/violet (forefoot zones) and cyan (heel), positioned at screen-space coordinates measured directly against the reference image (not guessed). Size and opacity both scale with the live 0–1 pressure reading for that zone (`0.22 → 0.82` opacity, `0.7× → 1.2×` size), so a resting foot looks faint and a loaded zone glows visibly.
- **Data mapping**: since the physical insole is a single sensor, both feet mirror the *same* live reading — `toe`→Toe, `inner`→1st MT, `outer`→5th MT, `heel`→Heel. This is a visual-completeness choice (matching the two-foot reference diagram), not a claim of bilateral instrumentation.
- **Static "+" crosshairs** on both feet — decorative reference marks matching the source diagram's own styling.
- **Live COP marker + fading trail** — shown only on the **left** foot, since that's the one actually carrying real x/y data; a white-filled, brand-indigo-ringed dot eases to each new position with a soft trailing glow behind it.
- Fades to 25% opacity when disconnected (crosshairs and the base photo stay fully visible; only the live glow layer dims).

## Screen 2 — Trends (`trends_screen.dart`)

Built directly from the shared `BiomechanicsEngine`'s rolling history buffer (no separate trend-tracking data structure).

- Header: "Trends" + "Last N processed samples this session".
- Empty state: icon + explanatory copy when no history exists yet.
- Four `_TrendCard`s, each a label + current value (colored to match its metric) over a 90px `fl_chart` line chart — curved line, gradient area fill fading to transparent, no axes/grid/touch interaction (pure sparkline):
  - Stability Index (red-pink, 0–100)
  - Cadence (green, 0–160 spm)
  - Impact Severity (orange, 0–100%)
  - Ischemic Pressure Integral (red, 0–100%)

## Screen 3 — Health (`insights_screen.dart`)

The plain-English read of what the engine currently sees — consolidates several web-app variants (3D view, heatmap legend, anatomy legend) into one card-based screen.

- **Clinical Summary card** — one dynamically-generated sentence (`_summarySentence`) that branches on connection state → calibration state → active anomaly flags → stability band, always in that priority order.
- **MLPI / Ischemic Risk stat pair** — two side-by-side cards, each: micro-label, Headline-Medium value, one-line plain-English caption underneath.
- **Automated Observations card** — either "No anomalies in the current rolling buffer" or a bulleted list of active flags with a red warning icon each.
- **"Why These Alerts Fire" card** — a paragraph spelling out the exact numeric thresholds behind every possible flag (e.g. ">8° corrected roll with lateral-dominant pressure" for ankle instability), reinforcing the "explainable, not black-box" promise directly in the UI.

## Screen 4 — Device (`device_screen.dart`)

Connection settings, dataset management, and session metadata — the only screen that isn't purely a read-only telemetry view.

- **ESP32 WebSocket Stream card**:
  - Endpoint + optional relay-endpoint fields with **inline validation** (non-empty + `ws://`/`wss://` scheme check) surfaced via `errorText`, not just a later runtime socket error.
  - **Four-state Connect button**: Disconnected (brand, "Connect") / Connecting (disabled, spinner, "Connecting…") / Connected (danger red, "Disconnect") / Error.
  - **Status row** (connected only): "Connected to \<url\>" + "Last update: HH:MM:SS" — data that previously existed in state but was never surfaced in the UI.
  - **Error state**: message in danger-red + an inline "Retry now" button that bypasses the exponential-backoff wait.
- **Session Metadata card** — Session ID + Trial ID fields.
- **Research Dataset card** — running sample count + save status, "Export CSV" (via `share_plus`) and "Clear" (with a confirmation dialog) buttons.
- **Backend Upload card** — upload endpoint + obscured bearer-token field, "Upload dataset" button with an inline spinner and a result/error message below.

## Shared components (`lib/shared/widgets/`)

- **`RoundedCard`** — the only card shape in the app; optional `onTap` wraps it in `Material`/`InkWell` for a ripple.
- **`MetricTile`** — label + value inside a small `RoundedCard`, optional value color override (used for the color-coded Stability Band).
- **`ConnectionBadge`** — pulsing dot (continuous 1400ms loop when live) + uppercase label. (The pulse `AnimationController` is built eagerly in `initState`, not lazily, after a dispose-time crash bug was found and fixed this project — see git history.)
- **`SegmentedToggle`** — pill-shaped, animated (260ms) live/simulation switch.

## Connectivity states → visual states

The Device screen's Connect button and the Today screen's `ConnectionBadge` are the two places connection state surfaces. As of the connectivity refactor (`CONNECTIVITY_PLAN.md`):

- Reconnect uses **capped exponential backoff with jitter** (1.5s → 30s ceiling) rather than a fixed 1.5s retry, so a genuinely offline device doesn't get hammered.
- A single malformed JSON frame on an otherwise-healthy link no longer shows a stale error banner — it's treated as a transient blip, not a disconnect.
- Entering simulation mode now actually disconnects any live socket (and vice versa) — previously both could run in the background simultaneously, silently corrupting the recorded dataset with interleaved live+simulated samples.

## Light / dark mode

Every screen and component is theme-aware via `Theme.of(context)` — there is no screen-specific light/dark branching outside `app_theme.dart` and the two or three spots (`FootPressureView`, `DiseaseSelector`) that need a literal color not expressible through `ThemeData` (e.g. the foot-map's background wash, the disease-chip inactive fill). `ThemeMode.system` is used app-wide — the app follows the OS setting, no in-app theme toggle exists.

## What's intentionally not built yet

See `BETTERMENTS.md` for the full list; the headline items relevant to UI/UX:

- No onboarding flow / first-run wizard (Device screen's Connect card *is* the entire setup flow, by design — see `CONNECTIVITY_PLAN.md`'s explicit scoping decision).
- No BLE transport or mDNS auto-discovery UI (manual `ws://ip:port` entry only).
- No dark-mode-specific asset for the plantar pressure photo — `feet.png` has a baked-in white canvas background, so a white rectangle is visible behind the foot silhouette in dark mode (a limitation of the source asset, not the code).
- No animated tab-switch transition (`IndexedStack` swaps instantly) or ring "breathing" idle animation — both are named as proposed additions in the companion Figma design file, not implemented in the app.

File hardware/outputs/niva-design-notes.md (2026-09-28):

# NIVA — physical design concept

Photorealistic concept images, generated with the built-in image-generation tool. These depict a proposed physical design, not an engineered or clinically validated device.

## Form and attachment
A compact rounded shin pod in pale grey-blue, with navy sides, one teal button and a single three-colour status light. Nominal envelope: 48 × 34 × 13 mm, subject to component packaging. A broad, smooth silicone ladder strap and shaped cradle locate the motion sensor on the lower shin above the ankle bones. The cradle has a defined orientation; calibrate after fitting.

A roughly 2.5–3 mm soft foot-shaped insert rests on the sandal footbed, underneath the foot. A toe-web slot accommodates rubber chappal posts, with sensor traces routed around it. A soft heel loop and removable low-profile instep keeper retain it where needed. In closed shoes and gumboots, the same insert fits inside and the flat tail routes up the leg; use only where there is sufficient clearance, without pressure at boot collars. For barefoot patients, place the insert in the supplied washable rubber grip sole with soft adjustable straps.

Offer size-matched left/right inserts rather than cut-to-size sensor sheets. Target fitting sequence: select size, seat inserts, close heel keepers, strap pods and confirm side/orientation on the phone. Under-one-minute fitting is a design target requiring timed field trials.

## Soft sensing surface
Five flexible pressure elements lie beneath the big toe, medial and lateral forefoot, lateral midfoot and heel. A thin flexible piezoelectric vibration film lies beneath the heel. Laminate them on flexible traces within a sealed TPU envelope between continuous soft closed-cell cushioning layers. No solder joints, plugs, battery, rigid circuit board or locally raised sensor bosses lie beneath the plantar surface. Heel vibration-film depth and cushioning require signal and pressure-distribution testing. Nothing electronic is visible through the top surface.

## Protected connection and service
An overmolded flat flexible tail exits the lateral heel and runs close to the ankle, retained at the shin strap. Rolled slack sits in a shallow cradle channel. Strain relief protects both ends. The covered connector stays above the foot. The insole and its tail replace together; the pods, straps, cradle and battery cartridges replace independently.

Pods use simple two-piece molded PC/ABS shells, service screws accessible off the body, and a replaceable perimeter gasket. Use common electronics and battery formats within serviceable cartridges. Soft parts use molded silicone, TPU and closed-cell foam. Avoid fabric sleeves, absorbent foam trays and exposed hook-and-loop fasteners. Validate chosen cleaning agents against every material and seal before specifying a disinfection procedure or ingress rating.

## Charging physically separated from wearing
There is no USB socket, inductive charger or charging circuit in either wearable pod. The battery is a sealed cartridge. Its release is on the rear of the pod and physically covered by the strapped cradle, so the pod must first be unclipped. Removing the cartridge disconnects the wearable. Only a removed cartridge fits the recessed charging wells in the case; a whole pod cannot fit. Dock contacts are shrouded inside the wells. The dock accepts USB power from a wall supply or power bank. Validate this mechanical exclusion with prototypes.

## Left/right control
Mirrored foot shapes, toe-web slots, heel cups and large molded L/R marks guide fitting. Left and right insole plugs and cradle keys use different, physically incompatible shapes; colour alone never determines side. Pod identity and insole side are checked electronically. The fitting screen includes a worker-guided right-foot lift confirmation and blocks test start if the reporting side is wrong. Mechanical keys prevent crossed assembly; correct placement on a person's anatomy still needs a fitting check.

## Health-camp use
Bluetooth control from the worker's own phone, with local storage and later synchronisation, is the proposed software behaviour. Green means valid acquisition, amber repeat, red recalibrate; none is a disease-risk colour. The phone also shows words and symbols.

The base kit contains paired shin units, size options and spare inserts, barefoot grip soles, spare straps, removable batteries, a charging cradle, USB cable and power bank in a gasketed polypropylene case with a removable smooth tray. The phone shown belongs to the worker. The optional knee-sound sensor is omitted from this base design to keep cost, cleaning and fitting effort down.

Image dimensions and small markings are illustrative. Prototype checks should cover pressure hotspots, traction, footwear clearance, fit time, left/right misuse, sensor calibration, signal quality and cleaning durability. Clinical screening accuracy and referral thresholds need separate validation.

## Images
- niva-worn-hero.png
- niva-health-camp-kit.png

## Generation prompts
Built-in image generation was used throughout.

### Hero
Use case: product-mockup
Asset type: photorealistic industrial design hero photograph, landscape 3:2.
Primary request: Design visualization of NIVA, a practical low-cost medical gait screening wearable, being worn by an adult rural Indian patient in simple rubber thong sandals. Show credible construction and how it attaches, no face visible.
Scene: shaded veranda of a modest primary health centre in North East India, plain clean concrete floor, chair softly blurred behind, daylight after rain but dry testing area. Crop from just below knees to floor. Medium-brown skin adult around 55 with natural skin texture, loose muted brown trousers rolled to below knees. Both feet standing naturally, one slightly ahead. Three-quarter front-side viewpoint focused on closest right shin and sandal, legs occupy most of photograph.
Product consistent physical design: Each foot wears an ordinary navy rubber Y-strap chappal. A very thin pale grey-blue #EAF0F2 full-length foot-shaped NIVA sensor insole lies ABOVE the sandal footbed, BELOW the foot and sandal straps, visible as a discreet 2.5mm pale rim at toes and heel. Its toe edge has a small slit between big and second toe to accommodate the existing thong post; sensors are entirely invisible and buried inside a smooth cushioned surface. A slim pale-grey soft heel retention loop and low-profile silicone instep keeper hold the insert against foot; do not add bulky forefoot straps. A single flat teal flexible sealed ribbon 8mm wide exits the OUTER rear heel rim, hugs the outer ankle and curves upward along lower leg to a small shin electronics pod, no loose round wires. Ribbon resembles a flexible TPU-coated flat strap, no hard parts at foot.
Pod: compact vertically oriented rounded rectangle approximately 48mm tall x 34mm wide x 13mm deep, pale grey-blue matte molded plastic, navy side seam, generous 7mm corner radii, on an obliquely anterolateral lower-shin cradle about 8cm ABOVE the ankle bones; never on ankle bone. Small navy NIVA wordmark near top, one circular flush teal button centered lower front, one tiny horizontal GREEN status light above button, small recessed R mark at bottom. A single 35mm wide navy smooth wipeable silicone ladder strap encircles lower shin and firmly locates the cradle; slim teal strap-end keeper visible, no textile or velcro. Flat teal ribbon is tucked close under strap and connects at pod base with protected flush entry. Left leg matching mirror assembly with small L mark, in background. Only one indicator lit per pod, no screen, no charging port, no flashy trim.
Style: extremely photorealistic professional medical product photography with honest material texture, soft natural side lighting, subtle shadows, 70mm lens feel, believable dimensions, restrained navy teal and grey palette. Trustworthy modest reusable screening equipment, not sporty or futuristic. Detail must show sandal footbed, soft insert rim, flat protected link and shin mounting clearly.
Text: only small 'NIVA' wordmark, tiny R or L molded side marking. No explanatory text, arrows, captions, overlays or watermark.
Avoid: visible sensor disks, hard lumps under sole, exposed copper or circuit boards, loose wire loops, thick orthopedic boot, ankle braces, smartwatches, LEDs in footbed, facial features, extravagant lab scene, medical outcome claims.

### Hero refinement
Use case: precise-object-edit. Refine this NIVA product photograph. Change ONLY the two navy straps encircling the lower shins: replace the visibly woven fabric texture with solid smooth matte navy silicone rubber, gently rounded edges, with a few molded ladder adjustment slots visible at the outer strap ends near the teal keepers. They must look wipe-clean, nonporous, practical medical straps. Preserve exactly the pod shapes and size, NIVA words, button and green status LED, protected teal flat cable, feet, sandal design, insole, environment, perspective, lighting and composition. Do not alter sandal strap textures. Photorealistic. No extra text.

### Kit
Use case: product-mockup
Asset type: second photograph in an industrial design proposal, landscape 3:2.
Input image: reference only for product identity, palette, shin pod design, strap and insole design. Create an entirely NEW photograph of the complete kit laid out on a health camp table, not an edit of the person's pose.
Primary request: Photorealistic NIVA reusable gait-screening kit as a health worker unpacks it at a rural health camp, tidy complete layout, clinically trustworthy, modest manufacture, believable components and no people. High three-quarter overhead viewpoint, diffused daylight, warm neutral tabletop, editorial product photography. Show every component fully within frame, no captions or infographics.
At rear: open modest navy polypropylene carry case with handle, two simple latches, grey gasket, smooth light grey removable wipeable molded tray, NO fabric or porous foam. Lid inside has a discreet printed fitting card of small simple foot/chair/walking pictograms. Small NIVA wordmark only. Case about 40cm wide.
Foreground center: one matching left and right full-length thin 2.5mm soft pale grey-blue insoles, asymmetric anatomical foot shape with obvious big-toe side, shallow soft heel cup and grey heel retention loop. Each has a small precise slot from front edge between the big-toe and second-toe regions so a chappal toe post can pass through. Top surface completely smooth, closed, cushioned, zero sensor dots, zero bumps, zero exposed electronics. Each insole has a tiny molded L or R and M size at heel. Teal 8mm-wide smooth flat protected flexible tails emerge from the outer heel edges, extend neatly upwards on table to the left and right shin pods. Distinct small covered connectors at pod base, no loose round wires.
Two identical compact pale grey-blue rounded rectangular shin pods from reference, about 48 x34 x13mm, navy sidewalls, small NIVA wordmark, tiny status LED unlit, single circular teal button and L/R mark, each mounted on navy silicone cradle with opened smooth navy silicone ladder strap and teal keeper. Maintain reference design proportions and visual identity. All straps solid nonporous silicone, not fabric.
To left, two extra pairs of insoles in S and L sizes neatly fanned/stacked, making six insoles total including medium foreground pair. Match construction and keep spare tails tidily coiled as flat ribbons, not cables. On right, two dark navy thin flexible rubber traction oversoles for barefoot patients, one underside-up to show broad shallow tread, one topside-up to show matching insole nest and soft adjustable forefoot/heel straps. These are simple open sandals that accept the same sensing inserts, no sensor lumps.
Within open case tray: two small sealed navy battery cartridges side by side in a dedicated charging cradle, each about 28 x22 x7mm, simple flat oblong blocks with protected edge contacts. Charging cradle physically separate from wearable pods. One short neatly coiled USB-C power cable and a compact unbranded power bank in adjacent tray recesses. A few spare smooth silicone strap parts in small recess. All equipment organized realistically with sufficient spacing.
A health worker's plain smartphone lies just outside case at upper right; simple screen with only 'NIVA', 'Ready', a small Bluetooth symbol, chair and walking pictograms. No disease score or diagnosis. Phone belongs to worker, no exaggerated tech.
Palette navy #14314B, teal #0B6F79, light grey-blue #EAF0F2. Real injection-molded polymer, soft satin silicone, slightly matte insole skin. No metallic luxury finishes. No optional knee sound sensor in this base kit. No exposed boards, hard objects under insoles, exposed sensor circles, fragile wires, branding other than NIVA, floating objects, scientific diagrams or marketing copy.

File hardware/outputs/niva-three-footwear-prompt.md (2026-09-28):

# NIVA — three footwear concepts

Created using the built-in image-generation tool, referencing the original NIVA hero design. Concept visualization; footwear clearance and attachment require physical fit testing.

## Generation prompt

Use case: product-mockup.
Create a photorealistic industrial design comparison board of NIVA worn in THREE DISTINCT TYPES OF FOOTWEAR. One landscape image, three equal-width vertical photo panels separated by slim white gutters. Simple small navy sans-serif headings at top of each panel, exactly "CHAPPAL", "SANDAL", "SHOE", left to right. No other explanatory captions.
Input reference: existing NIVA worn photograph. Preserve product identity from reference in all three panels: pale grey-blue small rounded rectangular shin pod, navy sidewall, small NIVA wordmark, tiny green status indicator, single circular teal button, tiny R, smooth nonporous navy silicone ladder strap around lower shin with teal keeper. Single slim flat teal sealed flexible connection exits pod bottom, hugs leg and routes along outer ankle to outer heel of insole. Match product scale, shape, colours and materials across all panels. No loose wires, screens or charging ports.
Each panel shows the SAME adult Indian patient's RIGHT lower leg and foot only, no face, natural medium-brown skin, rolled plain taupe trouser hem near top. Crop from below knee to floor, show entire footwear and entire shin pod with space above. Same right-side three-quarter lateral camera angle, toe pointing gently to left, consistent scale and soft daylight, neutral clean concrete floor with subtly blurred primary health centre wall. Photorealistic detailed real skin, realistic weight bearing, footwear and materials, no illustration or cutaway.
LEFT CHAPPAL: simple inexpensive navy rubber flip-flop with one Y-shaped thong upper and toe post between big and second toe. Toes exposed. Thin pale grey-blue NIVA sensing insert lies ON TOP of existing footbed and UNDER foot, visible as thin soft pale rim at toe and heel. Tiny slit in insert accommodates toe post. Discreet pale silicone heel retention loop as reference. Flat teal protected connection originates at lateral rear heel insert and follows ankle to pod. Show very clearly that chappal is a flip-flop not multi-strap sandal.
MIDDLE SANDAL: inexpensive practical brown/dark navy open-toe sandal, TWO wide transverse straps across forefoot and instep and an existing ankle/heel strap, NO toe post. Same thin pale NIVA insert sits ON sandal footbed and UNDER foot, a fine pale edge visible. Existing sandal heel strap retains assembly; do not add duplicate bulky retention straps. Route flat teal tail past outer heel through open side between straps, without pinching at buckle, then up ankle to identical shin pod. This shoe must unmistakably be a strappy open-toe sandal, different from flip-flop.
RIGHT SHOE: plain charcoal inexpensive closed-toe lace-up walking shoe, low collar, simple laces, matte canvas or synthetic upper, modest rubber sole, no brand or athletic graphics. Thin charcoal sock inside shoe ending just above collar. NIVA insert is fully concealed INSIDE shoe UNDER socked foot, do NOT show insole floating outside or on the outsole and do NOT expose toes. Flat teal tail emerges gently between sock and lateral shoe collar near rear, with a short soft grey protective sleeve at collar, lies flush to outer ankle and runs up to identical shin pod on skin. No connector inside shoe or underfoot; no cutting holes in shoe.
Design must read as SAME retrofit NIVA hardware adapted to three ordinary footwear types, not three different products. Keep all feet plausible and grounded. No glowing sensors, exposed sensor disks, underfoot electronics, anatomical x-rays, infographics, arrows, extra limbs or multiple feet per panel. Premium clarity but modest realistic community health equipment.

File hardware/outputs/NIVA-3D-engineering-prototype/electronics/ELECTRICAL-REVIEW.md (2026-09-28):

# NIVA pod — electrical design review, Revision C

**Status:** engineering prototype, Rev C.1.
- The schematic is one connected KiCad 9 hierarchy that passes ERC with 0 errors.
- The PCB is **routed**. KiCad DRC reports 0 errors and 0 unconnected items with schematic parity on.
- The cartridge strip, charging dock and insole flex (right and left) are separate KiCad projects. Each passes ERC and DRC.
- Nothing here has been independently reviewed, built, powered or measured. **Not released for fabrication:** Gerbers exist for review only.

## 1. What was wrong with Rev B, and what changed

| # | Rev B finding | Rev C resolution |
|---|---|---|
| E1 | Neither `.kicad_sch` file could be parsed by KiCad: every placed symbol was left unclosed (42 and 15 unbalanced parentheses). | The generator writes a closed record per symbol. All three sheets load in KiCad 9.0.9, with 65 components in Rev C.1 (63 electrical + 2 mounting holes; the two BAS416 became one BAV199). |
| E2 | Two separate projects were "merged by matching local net labels". This meant +3V3/GND and the four interface signals were **not** connected across the files. | One hierarchy: root `NIVA-pod.kicad_sch` → `Controller` and `Heel and indicator`. Rails use global power symbols; `PVDF_RAW`, `PIEZO_ADC`, `LED_R` and `LED_G` use hierarchical labels and sheet pins. |
| E3 | The official Espressif symbol library (github.com/espressif/kicad-libraries, 2026-07 snapshot) is saved in **KiCad 10** format (`20251024`), so KiCad 9.0.9 rejects it. | The ESP32-C3-MINI-1 symbol is down-converted by stripping four presentation-only tokens (`show_name`, `do_not_autoplace`, `in_pos_files`, `duplicate_pin_numbers_are_jumpers`). Pins and electrical types are unchanged. The official footprint (KiCad 7 format) is used unmodified. |
| E4 | VEXC was hard-wired to +3V3 at J1 pin 1. A short in the tail pulls down the MCU rail, and the "VEXC sense" divider measured +3V3, so it could never detect that fault. | VEXC is fed through R33 = 220 Ω with C18 = 1 µF, so a tail short draws 15 mA (0.05 W in R33) and the rail stays up. **Rev C.1:** VEXC is also the MCP3208 VREF (C19 1 µF at the pin), so every channel is ratiometric in hardware. CH6 now reads +3V3/2 (R31/R32, C16) against VEXC as a tail-fault monitor. |
| E5 | The ID line went straight to ADC CH7 with no filtering. | R34 3.3 kΩ + C17 1 µF, the same RC as the force channels. |
| E6 | Piezo clamps were left as "D_Small / select". | **Rev C.1:** D2 is one BAV199 (Nexperia low-leakage series pair, SOT-23, 3 pA typical), replacing the two BAS416 singles. KiCad's stock dual-diode symbols disagree with their own unit grouping, so D2 uses a project symbol whose pins state the datasheet pinning explicitly: 1 = A1 → GND, 3 = K1/A2 → PZ_BIAS, 2 = K2 → +3V3. The pinning is from the Nexperia BAV199 data sheet (April 2023), as quoted by two independent search results; the PDF host itself was blocked here. **Check the part marking against the purchased reel.** |
| E7 | The PVDF output filter was 1 kΩ/220 nF (723 Hz) for 2 kHz sampling, which is almost no anti-aliasing. | 1 kΩ/470 nF (339 Hz). It is still single-pole; see §4. |
| E8 | Decoupling was generic "C3–C5 100n on +3V3". | Assigned per pin: module 22 µF + 100 nF; ADC VDD 100 nF, VREF 1 µF; IMU VDD and VDDIO 100 nF each; LDO 4.7 µF in, 10 µF + 100 nF out; gauge 100 nF. |
| E9 | The battery was on a JST GH cable connector on top of the board, which is incompatible with a cartridge removed from the rear. | J2 is a 4-position spring-contact block on the board underside (2 × VBAT, 2 × GND). It reaches brass plates in the cartridge lid through a window in the bay ceiling. **The part is still to be selected**; the footprint is a labelled placeholder. |
| E10 | Service pads were a 2.54 mm pin header (too tall for the pod). | A Tag-Connect TC2030-NL footprint on the underside, reached through the empty cartridge bay. It has no charge path. |
| E11 | The button was a TL3342 with no height basis. | C&K KMR2 (KMR221G). Its 1.9 mm height comes from the KiCad library model and was used in the enclosure stack-up. |

## 2. ERC

`exports/NIVA-pod-ERC.rpt` (kicad-cli 9.0.9, all severities, KiCad default rule severities, **no exclusions**): **0 errors, 1 warning.**

- `pin_to_pin` — LSM6DSO32 SDx (bidirectional) is tied to GND, whose PWR_FLAG is a power output. The unused sensor-hub pins are tied to GND intentionally, following the ST pin table. This is left visible rather than suppressed. Confirm against the current ST datasheet (DS13210) before release.

## 3. Pin and boot review (ESP32-C3-MINI-1)

| GPIO | Net | Review |
|---|---|---|
| IO0 / IO1 | I2C_SDA / IMU_INT1 | Also XTAL_32K pins. That is acceptable because no 32 kHz crystal is fitted. |
| IO2 | I2C_SCL | Strapping pin that must be high at reset. The 4.7 kΩ I²C pull-up does this, and the MAX17048 (powered from VBAT) does not pull it low. |
| IO3 | BUTTON | Not a strapping pin. 10 kΩ pull-up; KMR2 to GND. |
| IO4/5/6 | SPI SCK/MISO/MOSI | Shared by the MCP3208 and IMU. The MCP3208 is limited to about 1 MHz SCLK at 2.7 V (2 MHz at 5 V), so firmware must switch clock rate per chip select. |
| IO7 / IO10 | CS_ADC / CS_IMU | — |
| IO8 | BOOT8 (pull-up only) | Must be high for UART download mode. Otherwise spare. |
| IO9 | BOOT9 | Strap: 10 kΩ pull-up; the service jig pulls it low for download. |
| IO18/19 | USB D−/D+ | Service pads only. There is no ESD protection: internal, jig-only access. |
| IO20 | LED_R | U0RXD; it is an input at boot, so the LED load is harmless. |
| IO21 | LED_G | U0TXD: **the ROM boot log will flicker the green emitter at reset.** Accepted for the prototype; firmware logs over USB. |
| EN | CHIP_EN | 10 kΩ / 1 µF RC reset delay (τ = 10 ms). |

All 15 exposed GPIOs are assigned (IO8 as a strap-only spare). Any new function needs an I/O expander.

## 4. Analog values (calculations, not measurements)

**Force channels (F1–F5), bench divider topology.** The FSR runs from VEXC to Fn_RAW, with 10 kΩ (0.1 %) to GND, then 3.3 kΩ + 1 µF into the ADC.
- Transfer: V = VEXC · 10k / (10k + R_FSR). This is **not** the Tekscan A201 op-amp reference circuit and does not inherit its linearity, drift or repeatability figures. Calibrate the complete insole stack as built.
- Low-pass fc = 1/(2π·3.3 kΩ·1 µF) = 48 Hz. At 200 Hz sampling the Nyquist attenuation is only about 7 dB. Plantar force content is mostly below 20–30 Hz, but impact transients alias. **Recommendation:** oversample (the MCP3208 has large headroom) and decimate in firmware.
- ADC settling: the 1 µF reservoir is about 50,000 × the MCP3208's ~20 pF sample capacitor, so charge-sharing error is below 0.003 %. The ADC's source-impedance limit does not apply at the pin.
- Current: at most 0.33 mA per saturated channel, 1.65 mA for all five (the brief's worst case).
- **VEXC is load-dependent, and that no longer matters to the reading.** Through R33 = 220 Ω, VEXC sags to about 2.94 V at full load, and one channel's load change moves VEXC by up to about 2 %. Rev C.1 drives the MCP3208 VREF from VEXC itself, so code = 4096 · 10k / (10k + R_FSR) whatever VEXC is: the ratio is formed in hardware, and **no firmware normalisation is needed**.
  - VREF range: the MCP3208 accepts VREF from 0.25 V to VDD (DS21298). VEXC is 2.94–3.3 V ≤ VDD, so this is in range.
  - VREF current: 100 µA typ / 150 µA max drawn from VEXC. C19 (1 µF at the VREF pin) supplies the conversion transients.
  - CH6 monitor: in normal operation it reads 4096 · 1.65 / VEXC, which is 2048–2299. On a tail short, VEXC (and so VREF) collapses below the 0.25 V minimum. Conversions are then invalid, but CH6 is driven toward full scale. Firmware treats CH6 outside about 2000–2400 as a tail fault and discards that block.
- Excitation is continuous (the Rev B decision is kept). Switching it every 5 ms cannot settle a 3.3 ms RC.

**Insert ID (CH7):** R30 = 10 kΩ 0.1 % from VEXC, and an ID resistor to GND on the insert's flex transition (above the collar). Code = 4096 · R_ID / (10k + R_ID), which is ratiometric. Assigned codes: **right medium 4.7 kΩ → 0.320 (1310)** and **left medium 47 kΩ → 0.825 (3378)**. Other sizes take further E12 values with at least 3 bins of separation after tolerance, e.g. 1k / 2.2k / 10k / 22k / 100k. An open tail reads 4095, and a short reads 0.

**ESD at J1:** no TVS is fitted. Each force and ID line reaches the ADC through 3.3 kΩ into 1 µF, so an 8 kV HBM event (100 pF → 0.8 µC) raises the reservoir about 0.8 V. The PVDF line is protected by the 100 kΩ series resistor and the BAS416 clamps. **System-level IEC 61000-4-2 testing is still required.**

**Heel PVDF buffer:**
- Film capacitance of about 1.4 nF (LDT0-028K class; confirm on the chosen part) with R43 = 10 MΩ bias gives a high-pass near 11 Hz.
- Clamp current is limited by R42 = 100 kΩ (a 70 V spike gives 0.7 mA).
- Offset budget: diode leakage × 10 MΩ = 3 pA × 10 MΩ = 30 µV typical (BAV199). The maximum leakage over temperature is larger; check the data sheet's maximum at 40 °C.
- MCP6001 unity-gain follower: 1 pA bias current, isolated from the 470 nF load by 1 kΩ.
- Output filter 339 Hz, single pole, for 2 kHz sampling: about 10 dB at Nyquist. Treat as exploratory. Decide the final filter and sample rate after experiment E3 (cable-motion noise).

**Status emitters:** red (Vf ≈ 2.0 V) through 1 kΩ gives about 1.3 mA; 570 nm yellow-green (Vf ≈ 2.1 V) through 680 Ω gives about 1.8 mA. Red and green together read as amber. Brightness and colour separation through the printed light pipe are untested. The colours signal recording quality only, never a clinical result.

## 5. Power integrity

- There is **no charger in the wearable**. The cartridge supplies VBAT through J2. Rev C.1 designs the rest as separate KiCad projects:
  - **Cartridge** (`cartridge/`): an EEMB LP502030-class cell whose integrated PCM is protection layer 1, a series 0805 polyfuse on every external P+ path as layer 2, the NTC routed to the dock only, and gold dock pads on the underside. No active parts.
  - **Dock** (`dock/`):
    - USB-C sink (5.1 k CC pull-downs, 1206 polyfuse) and an MCP73831-2 charger at 4.20 V, with I_REG = 1000 V / 10 kΩ = 100 mA (about 0.43 C of 230 mAh).
    - The charger's PROG pin reaches GND only through Q1. An LM393 window on the pack NTC turns Q1 off outside about 0–45 °C, and also when the NTC is open (no cartridge) or shorted. A floating PROG disables the MCP73831 (datasheet).
    - The temperature window is therefore enforced in hardware, with no firmware.
  - Both boards pass ERC and DRC. **Neither has been built, and the thresholds, charge termination and fault behaviour are unmeasured** (verification plan F4).
- TLV75533 dropout: 238 mV maximum at 500 mA (TI datasheet), scaling roughly with load. ESP-NOW/Wi-Fi TX bursts can reach a few hundred mA, so cell internal resistance, protection FETs, the two spring contacts and the dropout together set the usable cut-off. Measure the sag on the bench, then set a gauge-based firmware cut-off (bench item P1).
- MAX17048: about 23 µA continuous from VBAT; include it in the deep-sleep budget.
- Reverse insertion: the cartridge tab is asymmetric, so the cartridge only seats one way, and contacts only mate lid-inwards. There is no electrical reverse-polarity protection.

## 6. PCB — routed prototype (Rev C.1)

`NIVA-pod.kicad_pcb`: 4 layers (F.Cu signal, **In1.Cu solid GND plane**, In2.Cu signal, B.Cu signal), 34 × 48 × 1.0 mm, generated from the netlist by `work/build_niva_pcb.py`. Placement comes from `work/niva_layout.py`, which also drives the FreeCAD enclosure.

- **Rules:** 0.15 mm tracks with 0.127 mm clearance (0.3 mm for +3V3, VBAT and VEXC), and 0.5 / 0.25 mm through vias. These are inside common small-batch 4-layer capability, but they are not a specific fab's rules: confirm them with the chosen fab.
- **How it was routed:**
  1. Every GND pad (81, including the module's split thermal pad and the Tag-Connect pad) gets its own via to the In1 plane *before* routing, at the nearest spot that clears all other copper, holes, the board edge and the antenna keep-out.
  2. Freerouting 2.1.0 then routes the signal nets. It counts the plane-connected GND pads as unrouted because it does not credit the plane, so its log ends at "8 unrouted"; KiCad's connectivity check is the authority here.
  3. `finalize` imports the session, removes dangling stubs, adds GND pours on F.Cu, In2.Cu and B.Cu with solid pad connections, and fills them.
- **Result:** 547 track segments (F.Cu 665 mm, B.Cu 222 mm, In2.Cu 73 mm) and 126 vias (81 GND). The session in `work-routing/` was routed from the DSN before the Tag-Connect GND pad joined the fan-out; `finalize` adds that one via after import. Re-running Freerouting gives a different result each time (a repeat run left 6 nets open), so the committed session is the one that was checked.
- **DRC** (`exports/pcb/NIVA-pod-DRC.rpt`, KiCad 9.0.9, all severities, schematic parity on): **0 errors, 0 unconnected items, 0 parity issues, 0 footprint errors.** There are 3 warnings, all the ESP32-C3-MINI-1 footprint's own silkscreen clipped at the board edge. The module sits at the edge on purpose (antenna end out).
- **Board, enclosure and mounting:** the outline is notched around the four enclosure screw bosses with 0.4 mm clearance. Two M2 holes (H1, H2) go to bosses outside the battery bay. The other edges sit on housing ledges and are clamped by front-cover ribs. The FreeCAD audit against the routed PCBA shows only the two intended spring-contact preload intersections.
- **Antenna:** the module's antenna end is at the top board edge, with Espressif's footprint keep-out plus a board-level keep-out on all four layers (x 11–31, y 48.4–55 in the pod frame). No copper, via or pour is inside it. **RF performance and detuning by the housing and body are not verified.**
- **Not reviewed:**
  - return paths of the SPI clock and the analog rows over the split F.Cu pour;
  - PVDF input guarding;
  - thermal relief versus hand rework;
  - the fab's DFM check.

  The `fab-REVIEW-ONLY-NOT-RELEASED/` folder holds Gerbers, drill and placement files so that a reviewer can inspect them. It is **not** an order package; its `STATUS.txt` lists the blockers.

### Other boards (Rev C.1)

| Board | Layers / thickness | Routing | ERC / DRC |
|---|---|---|---|
| `cartridge/NIVA-cartridge` — 3.4 × 30 mm interconnect strip | 2 / 0.8 mm | hand-routed from `HAND` in `build_niva_pcb.py`: 17 segments, 3 vias, 0.3 mm power tracks, 0.15 mm gaps | 0 / 0 errors, 0 unconnected |
| `dock/NIVA-dock` — 58 × 56 mm charging dock | 2 / 1.6 mm | Freerouting plus GND pours: 166 segments, 10 vias | 0 / 0 errors, 0 unconnected |
| `insole/NIVA-insole-R`, `-L` — sensing flex (hold H1) | 2 / 0.12 mm polyimide; **F.Cu only underfoot** | generated lanes, 117 segments (3.3 m of 0.25 mm lanes), 8 vias, all above the collar | 0 / 0 errors, 0 unconnected |

The insole flex's FSR windows expose both comb nets under one coverlay opening on purpose, because the FSR film bridges them. The footprint declares `allow_soldermask_bridges`, so DRC reports no mask bridge.

## 7. Open electrical items before any fabrication release

1. Independent schematic and layout review; fab DFM on the pod, dock and flex; return-path and RF review of the pod.
2. Select the pod J2 and dock J2 spring-contact parts, and replace the placeholder land patterns and envelope models.
3. Confirm the MAX17048 TDFN-8 land pattern against the ADI package drawing (its 3D model is an envelope), and the BAV199 marking and pinning on the purchased reel.
4. Confirm the LSM6DSO32 unused-pin handling and the KMR2 travel and force.
5. Bench: regulator sag during radio bursts, deep-sleep current, ADC noise with VREF = VEXC, and the CH6 tail-fault flag.
6. Run the E3 cable-motion test before fixing the PVDF filter and sample rate.
7. Cartridge and dock: a purchased cell lot, the NTC value, the polyfuse part, charge termination and the thermal-window trip points, all measured (`../VERIFICATION-PLAN.md` F4).
8. Insole flex: choose and characterise the FSR ink film; test fatigue, sweat ingress and the ID codes (`../VERIFICATION-PLAN.md` F2, F3, F6, S7).

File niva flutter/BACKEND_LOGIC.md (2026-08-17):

# Backend / Data Logic

There is no application server in this repo — "backend" here means three things: the **ESP32 firmware** producing data, the **browser-local dataset store** persisting it, and the **optional external upload** that ships a CSV export to a research API you provide. This doc covers all three plus the transport layer connecting them.

```mermaid
flowchart LR
    subgraph Device["ESP32 firmware"]
        FSR["FSR + piezo sensors"] --> Cal["Zero-load calibration"] --> Pkt["JSON / CSV packet, 10 Hz"]
    end
    Pkt -- "WebSocket :81" --> WS["useSensorData.ts"]
    Pkt -- "USB Serial 115200 baud" --> Serial["Web Serial reader"]
    WS --> Engine["BiomechanicsEngine.process()"]
    Serial --> Engine
    Sim["simulationEngine.ts"] --> Engine
    Engine --> UI["Dashboard state"]
    Engine --> Queue["Dataset queue (in-memory)"]
    Queue -- "flush every 1s" --> IDB["IndexedDB\ngaitguard-nexus-datasets"]
    IDB -- "exportTelemetryCsv()" --> CSV["CSV blob"]
    CSV -- "multipart POST" --> API["VITE_DATASET_UPLOAD_URL\n(your research backend)"]
```

## 1. Firmware — the actual data source

Active sketch: `niva arduino/niva_hardware/niva_hardware.ino`

- **Pins**: heel `32`, inner `33`, outer `34`, toe `35`, piezo `36`, all analog, 12-bit ADC (`analogReadResolution(12)`, range 0–4095).
- **IMU**: MPU6050 on I2C (SDA 21, SCL 22) supplies live `pitch` / `roll` / `accZ`.
- **WiFi**: WiFiManager captive portal (`NIVA-GaitGuard-AP`), plus mDNS `ws://niva.local:81`.
- **Calibration**: 60-sample zero-load tare, persisted in NVS. Send `calibrate` / `tare` over WebSocket or Serial to re-tare.
- **Loop rate**: gated to `STREAM_INTERVAL_MS = 50` (20 Hz).
- **Output — both at once, every tick**:
  - **WebSocket** (`WebSocketsServer` on port `81`): JSON, e.g. `{"heel":12.00,"inner":8.00,"outer":3.00,"toe":1.00,"piezo":0.00,"pitch":-2.10,"roll":1.40,"accZ":9.78}`.
  - **USB Serial** (115200 baud): the same 8 values as a bare CSV line.

A smaller variant remains at `niva arduino/esp32_gaitguard_wifi_manager/esp32_gaitguard_wifi_manager.ino` (hardcoded Wi-Fi, no IMU/OLED, `pitch`/`roll`/`accZ` sent as `0.0`). Packet shape is the same.

## 2. Transport into the browser

Two independent paths feed the same downstream pipeline; only one is active at a time (checked via `isConnected`/`isSimulating` guards so they don't fight over the engine).

### 2a. USB Serial — `MainDashboard.tsx` (`connectSerial`/`disconnectSerial`)

- Uses the browser's **Web Serial API** (`navigator.serial`), which only exists in Chromium browsers over `localhost` or HTTPS — the dashboard checks for it (`isSerialSupported`) and shows a warning banner if unavailable.
- `port.open({ baudRate: 115200 })`, then pipes the raw byte stream through a `TextDecoderStream`, buffers partial lines, and splits on `\r?\n`.
- Each complete line goes through **`parseEsp32CsvLine`** (`src/utils/esp32Telemetry.ts`):
  ```ts
  const NON_DATA_PREFIXES = ['CALIBRATING', 'SYSTEM_', 'H,I,O,T'];
  ```
  Lines starting with these (firmware status/header lines) are ignored. Otherwise the line is split on `,`, requires **≥ 8 numeric fields**, and is destructured positionally: `heelRaw, mt1Raw, mt5Raw, toeRaw, piezoPeak, pitchDeg, rollDeg, accZ`. Anything that doesn't parse cleanly returns `null` and is silently dropped (no error surfaced per-line — only connection-level errors are shown).
- On disconnect, the reader is cancelled and its lock released defensively (both wrapped in empty `catch` blocks, since re-cancelling an already-closed stream throws) before the port itself is closed.

### 2b. WiFi WebSocket — `src/hooks/useSensorData.ts`

This hook resolves *which* URL to connect to and handles a browser-specific restriction the serial path doesn't have to deal with:

- **URL resolution priority**: `?esp32ws=` query param → `localStorage['gaitguard:nexus:ws-endpoint']` → `VITE_ESP32_WS_URL` env var → hardcoded fallback `ws://10.249.106.94:81`. Whichever wins is written back into `localStorage`, so opening a shared link once "pins" that device for future visits.
- **Local host detection**: if a hostname looks like an ESP32 AP/hotspot address (`localhost`, `127.0.0.1`, or RFC1918 private ranges `10.x`, `192.168.x`, `172.16–31.x`) and no port was specified, it defaults the port to `81`.
- **Mixed-content problem**: browsers refuse to open a plain `ws://` socket from a page served over `https://` (GitHub Pages is HTTPS). The hook detects this (`isBlockedByMixedContent`) and, if a **relay URL** is configured (`wss://...`, also resolvable from query param/localStorage/env), rewrites the connection to go through the relay instead, appending the real target as a query parameter (default key `target`, configurable via `VITE_ESP32_WS_RELAY_TARGET_KEY`). If no relay is configured, it surfaces a `connectionHint` telling the user to add one or use plain HTTP locally.
- **Reconnect**: on any socket close, a `1500ms` timer fires `connect()` again automatically, looping for as long as the component is mounted.
- **Malformed JSON** from the socket sets an error string rather than crashing.

Data lands in React state as `wsData`; `MainDashboard.tsx`'s `applyWsFrame` then normalizes field names (accepting either `inner`/`mt1` and `outer`/`mt5` as aliases, and either `impact`/`piezo`) before building the same `RawSensorPacket` shape the serial and simulation paths produce.

## 3. Processing — one engine, three sources

Regardless of source (`usb`, `ws`, or `sim`), every packet is funneled through **the same `BiomechanicsEngine` instance** (`biomechanicsRef.current.process(packet)`), so calibration state, step counting, and cadence timing stay consistent no matter where the data came from. This is deliberate: it's what lets the simulator's output be treated as "real" data for demo/training purposes.

## 4. On-device dataset store — `src/utils/telemetryDatasetStore.ts`

An IndexedDB database, `gaitguard-nexus-datasets` (version `2`), single object store `esp32_samples`, `keyPath: 'id'` with `autoIncrement`. Indexes on `timestampMs`, `source`, `sessionId`, `diseaseLabel`, `mode` (created idempotently in `onupgradeneeded`, so re-opening an older DB adds any indexes that are missing rather than failing).

Each row (`TelemetrySample`) carries: `timestampMs, source ('usb'|'ws'|'sim'), sessionId, trialId, diseaseLabel, mode ('live'|'simulation'), heel, inner, outer, toe, impact, pitch, roll, accZ`. `sessionId`/`trialId` fall back to `'session-unassigned'`/`'trial-001'` if left blank.

Exposed functions:
- `insertTelemetrySamples(samples[])` — batched `add()` calls inside one `readwrite` transaction.
- `getTelemetrySampleCount()` — `store.count()`.
- `getLatestTelemetrySamples(limit)` — walks the `timestampMs` index **backwards** (`direction: 'prev'`) collecting up to `limit` rows, then reverses the result so callers get oldest-first.
- `clearTelemetryDataset()` — wipes the store.
- `exportTelemetryCsv()` — pulls effectively all rows (`getLatestTelemetrySamples(1_000_000)`), builds a CSV with a fixed 14-column header, CSV-escaping any field containing a comma/quote/newline.

### Write path — queue, don't write per-packet

`MainDashboard.tsx` never calls `insertTelemetrySamples` directly from the hot path. Each processed packet is pushed onto an in-memory ref array (`datasetQueueRef`, via `enqueueDatasetSample`), and a **separate 1-second interval** (`flushDatasetQueue`) drains that queue into IndexedDB in one batch:

```ts
useEffect(() => {
  const intervalId = window.setInterval(() => void flushDatasetQueue(), 1000);
  return () => { window.clearInterval(intervalId); void flushDatasetQueue(); }; // flush once more on unmount
}, [flushDatasetQueue]);
```

- A `isFlushingDatasetRef` guard prevents overlapping flushes if a write is slow.
- **On failure, the batch is put back at the front of the queue** (`datasetQueueRef.current = [...batch, ...datasetQueueRef.current]`) so a transient IndexedDB error doesn't silently drop samples — they're retried on the next tick.
- At 10 Hz sampling this means up to ~10 samples can be buffered in memory before ever touching disk, trading a small durability window for far fewer IndexedDB transactions.

## 5. Export & upload — `src/utils/researchUpload.ts`

There is no bundled server — you point this at your own API via env vars (`.env.local`, Vite-style `VITE_*` prefix required to be exposed to the browser bundle):

```bash
VITE_DATASET_UPLOAD_URL=https://your-api.example.com/upload
VITE_DATASET_UPLOAD_TOKEN=your_optional_bearer_token
```

`uploadDatasetCsvToBackend({ csvContent, sampleCount, metadata })`:
1. Throws immediately if `VITE_DATASET_UPLOAD_URL` isn't set (checked client-side, before any network call).
2. Wraps the CSV string in a `Blob` (`text/csv;charset=utf-8;`) and builds `multipart/form-data`:
   - `file` — the CSV blob, named `gaitguard_esp32_dataset_<ISO timestamp with `:`/`.` replaced by `-`>.csv`
   - `sampleCount`, `generatedAt` (ISO timestamp), `datasetType: 'esp32-biomechanics'`
   - `sessionId`, `trialId`, `diseaseLabel` (only appended if present in `metadata`)
3. Adds `Authorization: Bearer <token>` if `VITE_DATASET_UPLOAD_TOKEN` is set.
4. `fetch(endpoint, { method: 'POST', body: formData, headers })`. Response body is parsed as JSON or text depending on `content-type`; a non-2xx status throws using the response body as the error message (or a generic fallback).
5. On success, returns `{ statusCode, message, location?, responseBody }` — `location` is pulled out of the JSON response body if the backend returns one (e.g. a URL to the stored file), otherwise `undefined`.

`MainDashboard.tsx`'s `handleUploadDataset` orchestrates the whole export-and-ship flow: force a `flushDatasetQueue()` first (so nothing in the in-memory queue is missed), re-check the sample count, build the CSV, then call the upload function — surfacing status text at each step (`"Flushing latest samples..."` → `"Preparing CSV..."` → `"Uploading..."` → `"Upload complete (...)"`).

**Manual CSV export** (`handleExportDataset`) is a separate, purely client-side path — no network call at all — that builds the same CSV via `exportTelemetryCsv()` and triggers a browser download via an `<a download>` + `Blob` object URL, so it works even with no upload endpoint configured.

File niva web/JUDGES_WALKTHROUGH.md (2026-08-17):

# GaitGuard Nexus: Algorithm and Data Walkthrough

## 1) Data Contract (Input Packet)

All pipeline logic is built around one packet shape:

- heel
- inner
- outer
- toe
- impact
- pitch
- roll
- accZ
- timestampMs

Primary type definitions:

- `src/utils/biomechanicsEngine.ts` (this `niva web` directory)

Transport-specific parsing:

- USB CSV parsing: `src/utils/esp32Telemetry.ts`
- WiFi JSON parsing and reconnect: `src/hooks/useSensorData.ts`

## 2) End-to-End Processing Path

Per packet flow:

1. transport ingest
2. packet normalization and validation
3. biomechanics engine processing
4. metrics to dashboard state
5. dataset persistence
6. export or backend upload

Coordinator file:

- src/pages/MainDashboard.tsx

## 3) Algorithm Map by File

### A) Transport and Parsing

File: src/utils/esp32Telemetry.ts

- CSV line parser from ESP32 serial stream
- filters firmware non-data lines
- numeric validation and frame construction

File: src/hooks/useSensorData.ts

- WebSocket ingest from ESP32 WiFi endpoint
- JSON parse with malformed-frame handling
- automatic reconnect loop

### B) Core Biomechanics Engine

File: src/utils/biomechanicsEngine.ts

Algorithms implemented:

1. Noise filtering
- EMA on heel, inner, outer, toe
- alpha defaults in engine options

2. Pressure normalization
- raw pressure transformed to bounded percent domain
- normalized pressure ratios computed from total pressure

3. Contact detection
- stance versus swing using total pressure threshold

4. Heel strike detection
- impact threshold + heel threshold + heel-rise rule + state transition guard
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

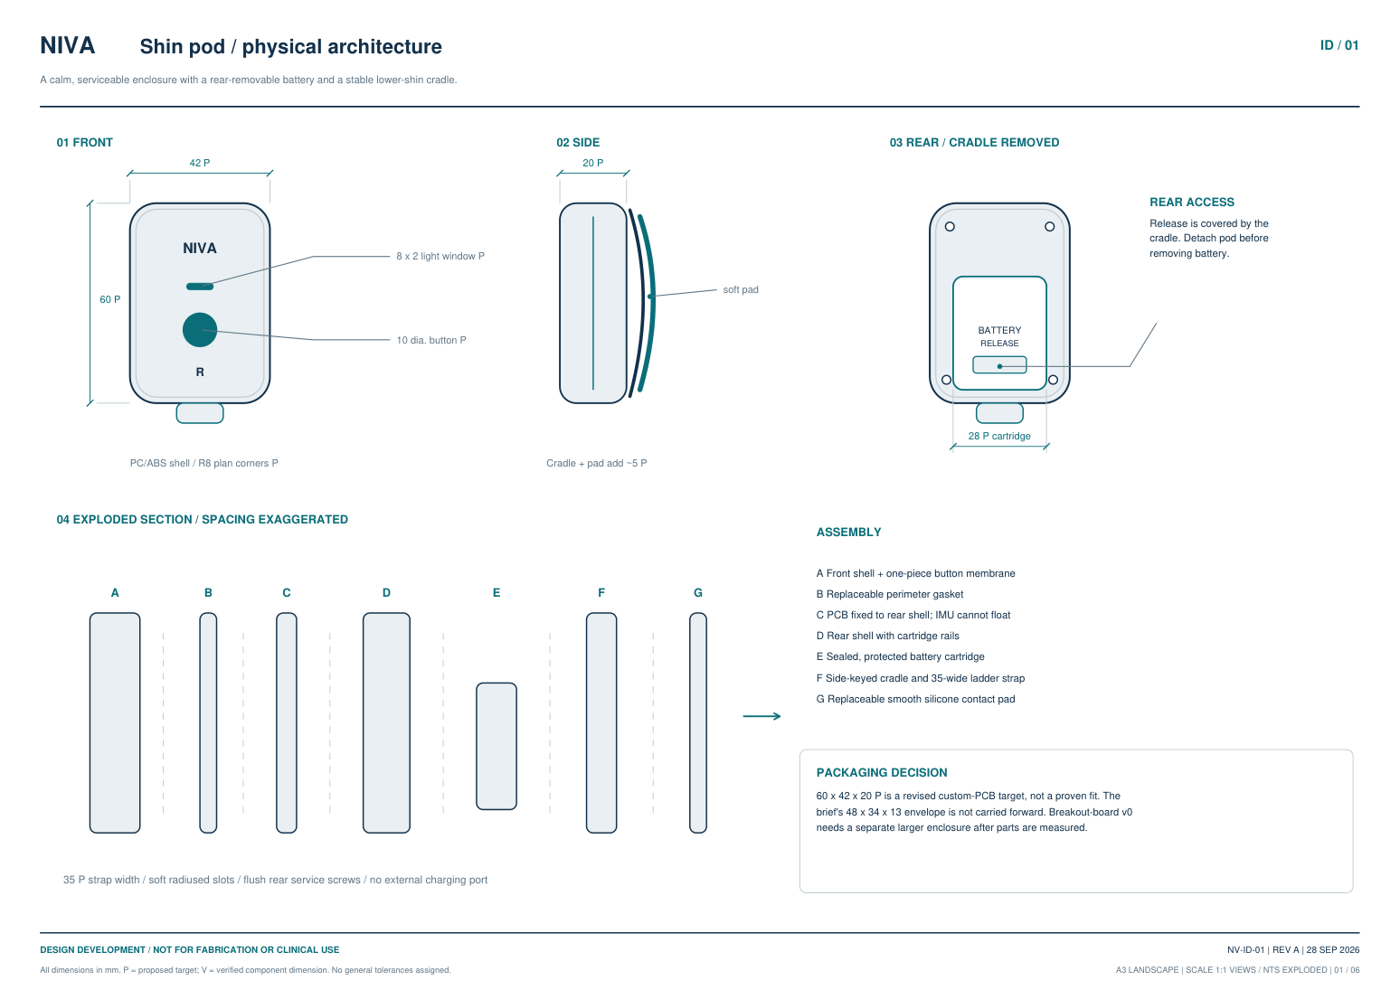
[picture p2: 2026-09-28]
hardware/work/blueprint-01.png

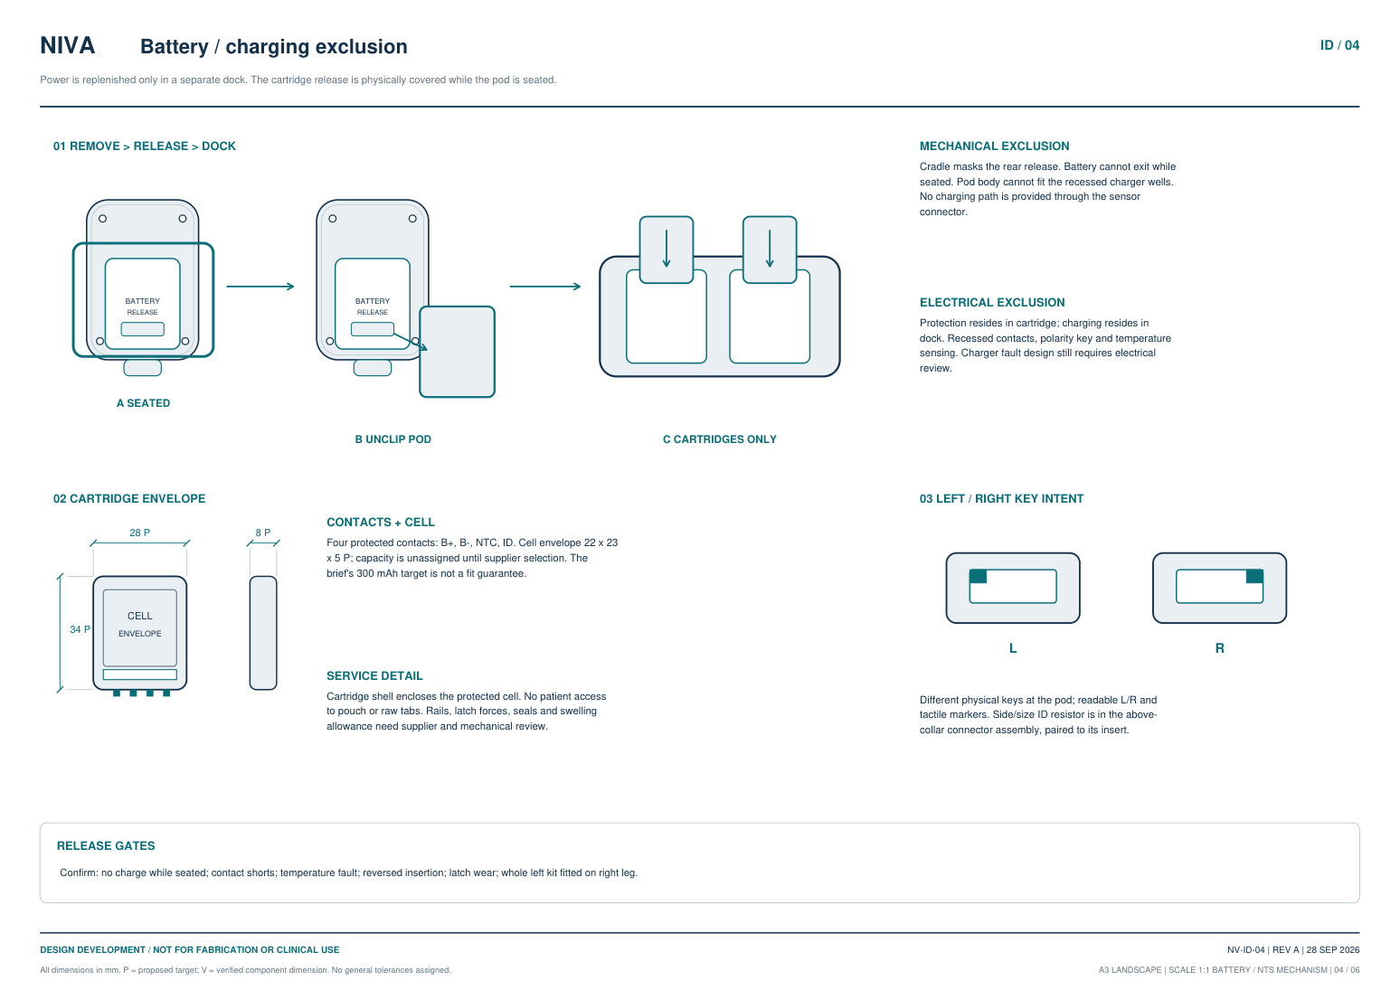
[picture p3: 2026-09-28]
hardware/work/blueprint-04.png

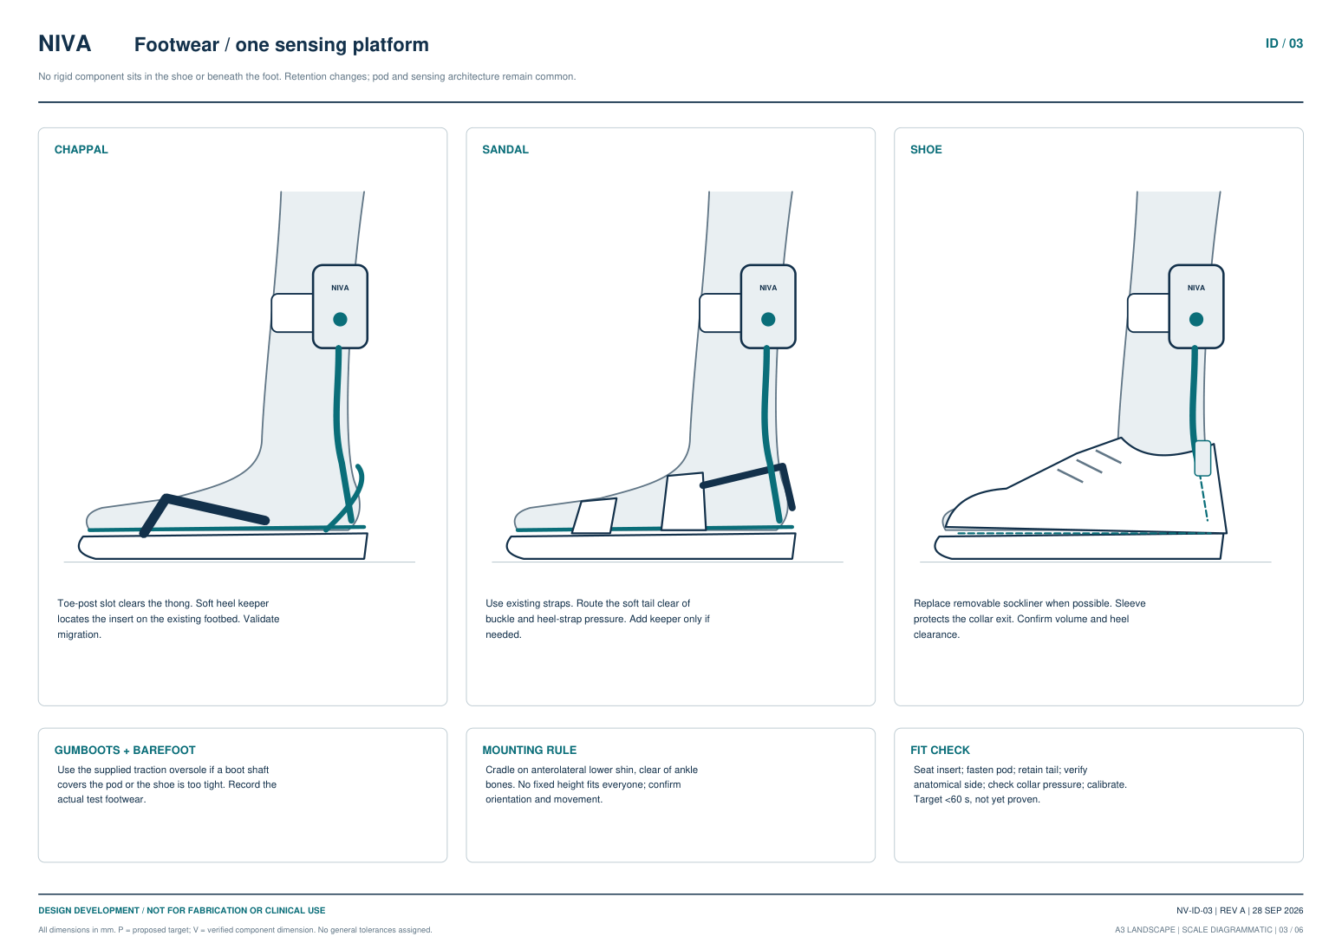
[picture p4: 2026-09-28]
hardware/work/blueprint-03.png

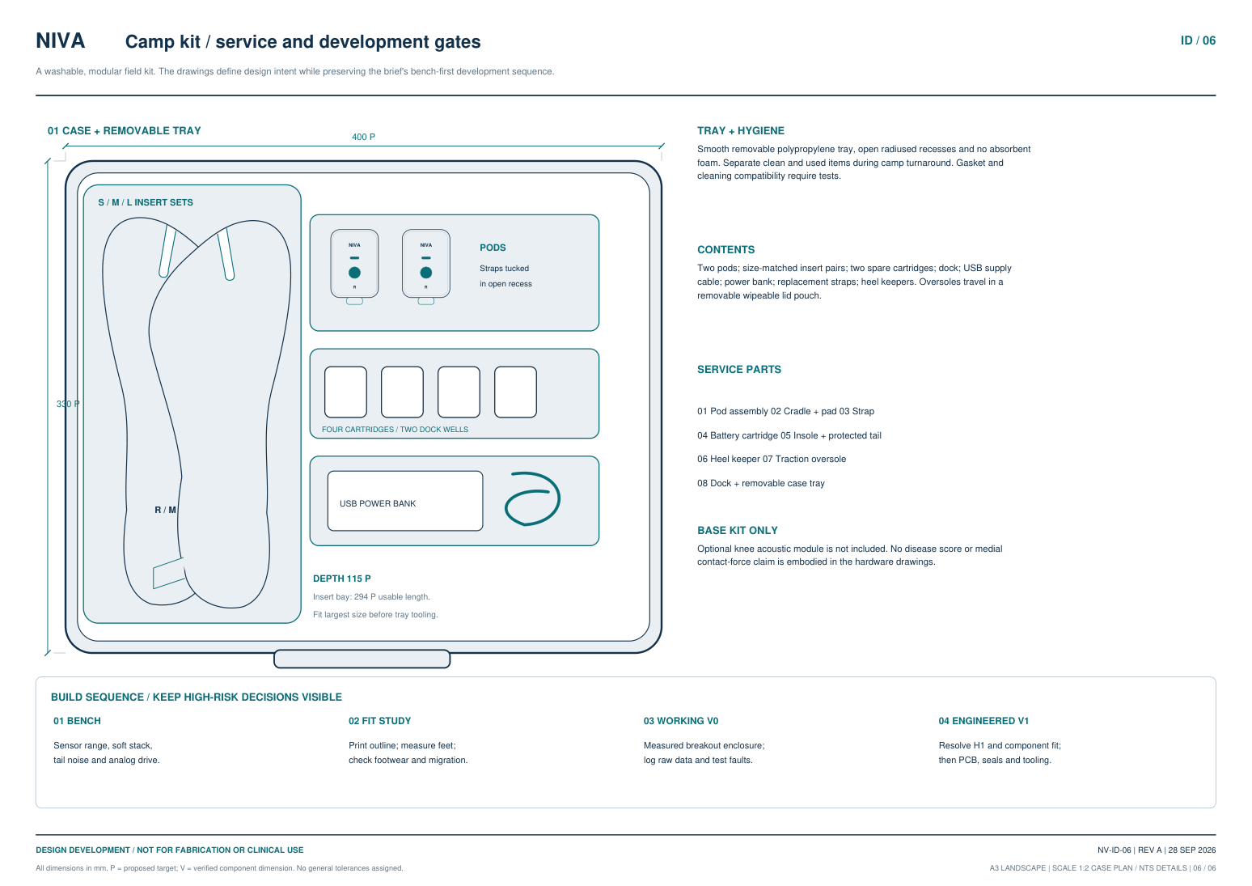
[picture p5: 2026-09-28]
hardware/work/blueprint-06.png

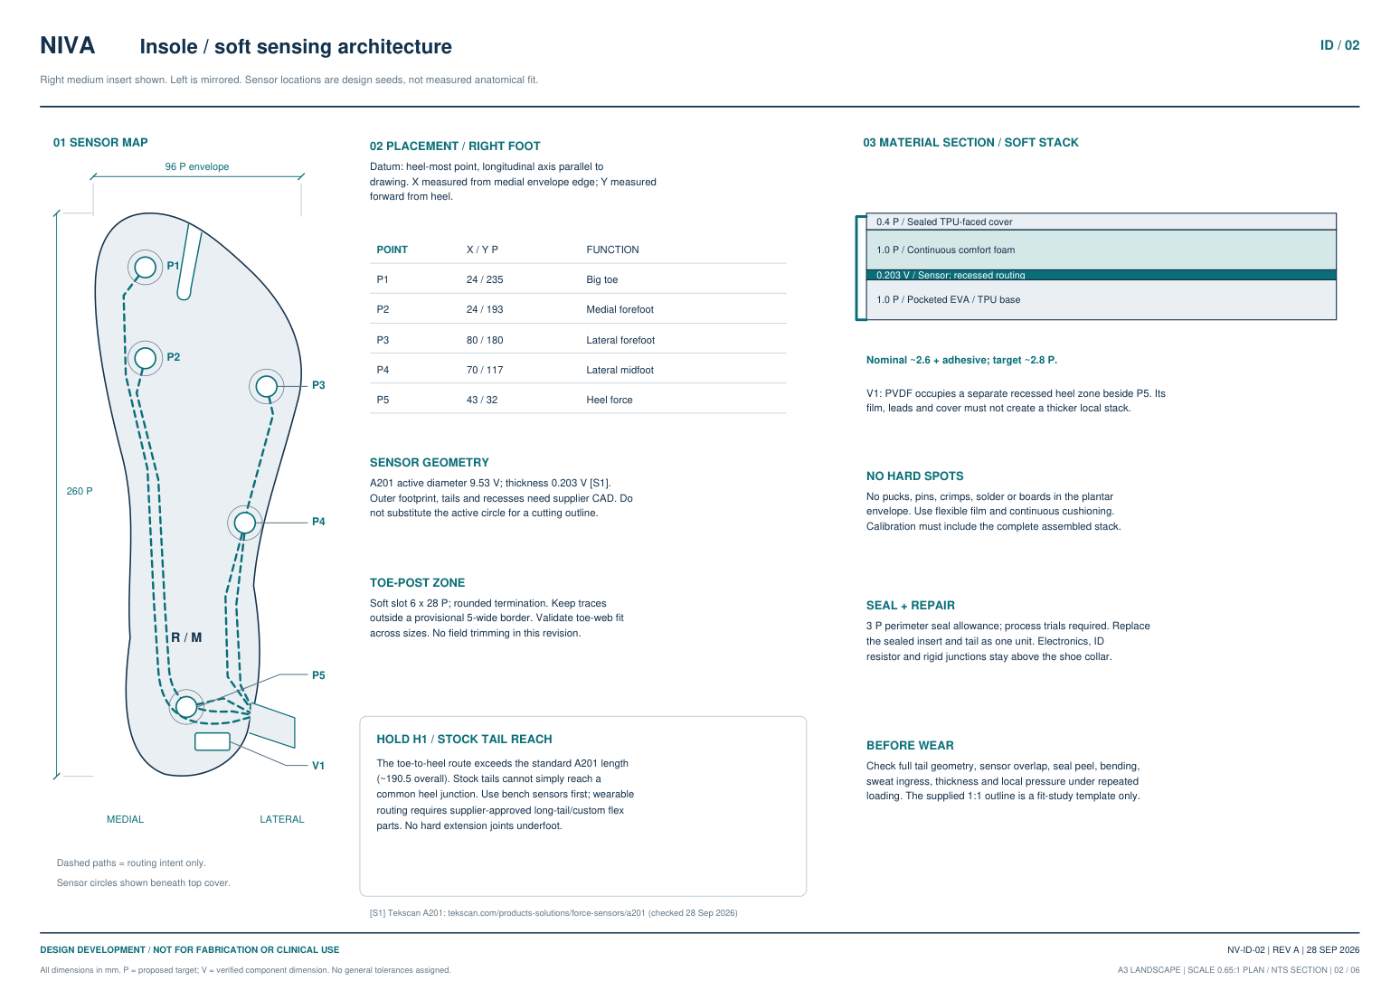
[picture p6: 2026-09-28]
hardware/work/blueprint-02.png

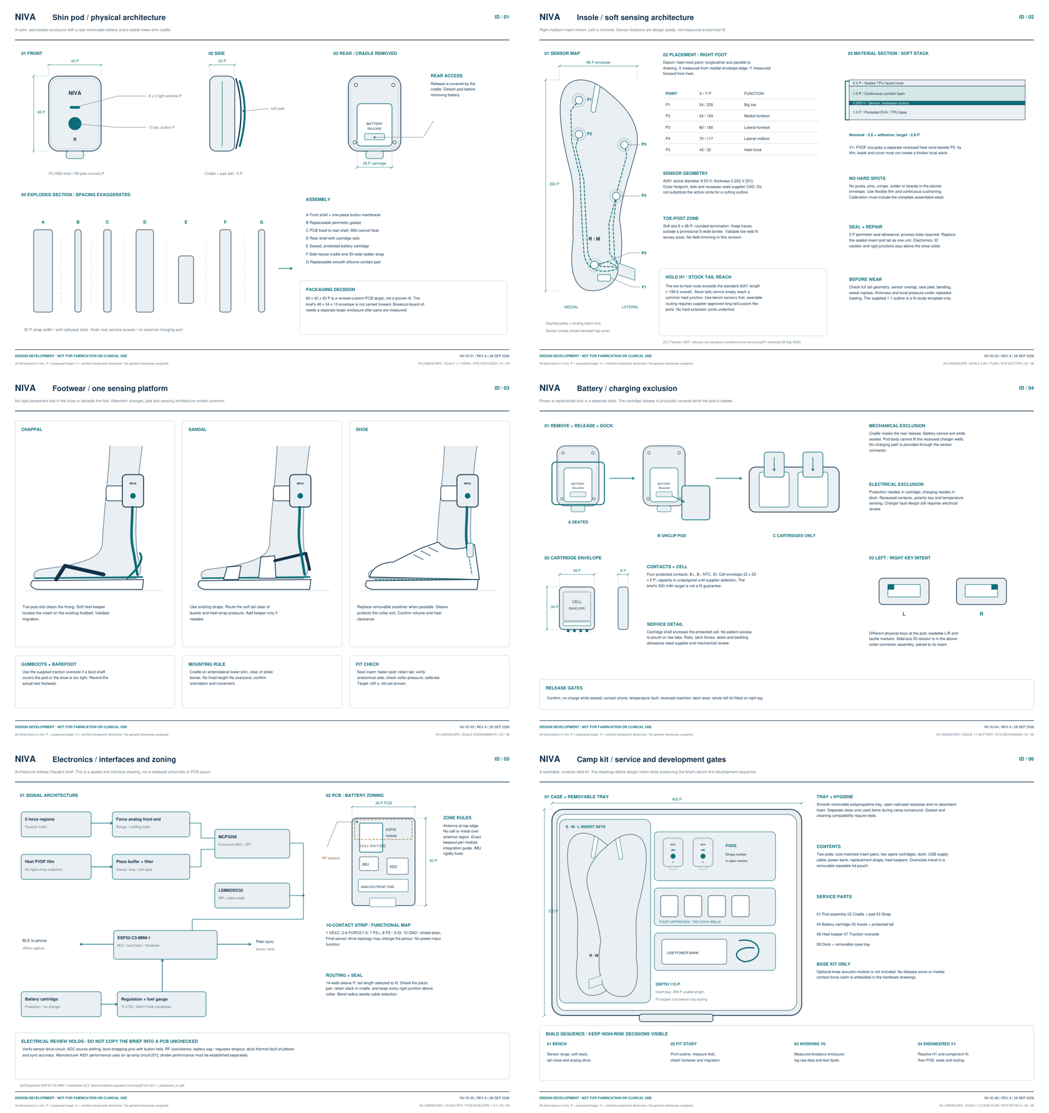
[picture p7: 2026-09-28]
hardware/work/blueprint-contact.png

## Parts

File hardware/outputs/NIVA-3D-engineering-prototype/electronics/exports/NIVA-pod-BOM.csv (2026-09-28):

Reference | Value | Footprint | MPN | QUANTITY
C1,C17-C19,C40 | 1u | Capacitor_SMD:C_0603_1608Metric |  | 5
C2 | 22u 6.3V X5R | Capacitor_SMD:C_0805_2012Metric |  | 1
C3-C5,C8,C9,C16,C20,C42 | 100n | Capacitor_SMD:C_0603_1608Metric |  | 8
C6 | 4.7u 10V X5R | Capacitor_SMD:C_0603_1608Metric |  | 1
C7 | 10u 6.3V X5R | Capacitor_SMD:C_0603_1608Metric |  | 1
C11-C15 | 1u X7R | Capacitor_SMD:C_0603_1608Metric |  | 5
C41 | 470n | Capacitor_SMD:C_0603_1608Metric |  | 1
D2 | BAV199 | Package_TO_SOT_SMD:SOT-23 | BAV199,215 (Nexperia) low-leakage series pair, SOT-23 | 1
D4 | RED 0603 | LED_SMD:LED_0603_1608Metric |  | 1
D5 | YELLOW-GREEN 570nm 0603 | LED_SMD:LED_0603_1608Metric |  | 1
J1 | INSERT TAIL (JST GH 10, keyed overmould) | Connector_JST:JST_GH_SM10B-GHS-TB_1x10-1MP_P1.25mm_Horizontal | SM10B-GHS-TB | 1
J2 | CARTRIDGE SPRING CONTACTS (part to select) | NIVA:SpringContact_1x04_P2.54mm_Vertical_SMD |  | 1
R1-R3,R6 | 10k | Resistor_SMD:R_0603_1608Metric |  | 4
R4,R5 | 4.7k | Resistor_SMD:R_0603_1608Metric |  | 2
R11-R15,R30 | 10k 0.1% | Resistor_SMD:R_0603_1608Metric |  | 6
R21-R25,R34 | 3.3k | Resistor_SMD:R_0603_1608Metric |  | 6
R31,R32 | 10k 1% | Resistor_SMD:R_0603_1608Metric |  | 2
R33 | 220 | Resistor_SMD:R_0603_1608Metric |  | 1
R40-R42 | 100k | Resistor_SMD:R_0603_1608Metric |  | 3
R43 | 10M | Resistor_SMD:R_0603_1608Metric |  | 1
R44,R45 | 1k | Resistor_SMD:R_0603_1608Metric |  | 2
R46 | 680 | Resistor_SMD:R_0603_1608Metric |  | 1
SW1 | KMR221G (C&K KMR2) | Button_Switch_SMD:SW_Push_1P1T_NO_CK_KMR2 |  | 1
U1 | ESP32-C3-MINI-1-N4 | NIVA:ESP32-C3-MINI-1 | ESP32-C3-MINI-1-N4 | 1
U2 | MCP3208-CI/SL | Package_SO:SOIC-16_3.9x9.9mm_P1.27mm | MCP3208-CI/SL | 1
U3 | LSM6DSO32TR | Package_LGA:LGA-14_3x2.5mm_P0.5mm_LayoutBorder3x4y | LSM6DSO32TR | 1
U4 | MCP6001T-I/OT | Package_TO_SOT_SMD:SOT-23-5 | MCP6001T-I/OT | 1
U5 | TLV75533PDBVR | Package_TO_SOT_SMD:SOT-23-5 | TLV75533PDBVR | 1
U6 | MAX17048G+T10 | Package_DFN_QFN:TDFN-8-1EP_2x2mm_P0.5mm_EP0.8x1.2mm | MAX17048G+T10 | 1

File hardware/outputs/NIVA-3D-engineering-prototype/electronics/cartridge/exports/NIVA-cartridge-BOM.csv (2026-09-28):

Reference | Value | Footprint | MPN | QUANTITY
F1 | PTC 0805 hold>=0.5 A, >=6 V | Fuse:Fuse_0805_2012Metric | to select (e.g. 0805 resettable, I_hold 0.5 A, V_max >= 6 V) | 1
J1 | CELL LEADS (+, NTC, -) | NIVA_power:WirePads_1x03_P1.8mm |  | 1
J2 | TO LID PLATES (P-, P-, P+, P+) -> pod J2 | NIVA_power:WirePads_1x04_P1.7mm |  | 1
J3 | DOCK PADS (P+, NTC, P-), underside | NIVA_power:ContactPads_1x03_P6.0mm |  | 1

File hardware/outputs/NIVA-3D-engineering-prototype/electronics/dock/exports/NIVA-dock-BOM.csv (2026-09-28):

Reference | Value | Footprint | MPN | QUANTITY
C1,C2 | 4.7u 10V | Capacitor_SMD:C_0603_1608Metric |  | 2
C3,C4 | 100n | Capacitor_SMD:C_0603_1608Metric |  | 2
D1 | AMBER 0805 (charging) | LED_SMD:LED_0805_2012Metric |  | 1
F1 | PTC 1206 hold 0.5 A | Fuse:Fuse_1206_3216Metric |  | 1
J1 | USB-C 6P power-only | Connector_USB:USB_C_Receptacle_GCT_USB4125-xx-x_6P_TopMnt_Horizontal | GCT USB4125 class | 1
J2 | SPRING PINS TO CARTRIDGE (P+, NTC, P-) | NIVA_power:SpringPins_1x03_P6.0mm_Vertical |  | 1
Q1 | 2N7002 | Package_TO_SOT_SMD:SOT-23 |  | 1
R1,R2 | 5.1k | Resistor_SMD:R_0603_1608Metric |  | 2
R3 | 10k 1% | Resistor_SMD:R_0603_1608Metric |  | 1
R4 | 1k | Resistor_SMD:R_0603_1608Metric |  | 1
R5 | 22k 1% | Resistor_SMD:R_0603_1608Metric |  | 1
R6 | 43k 1% | Resistor_SMD:R_0603_1608Metric |  | 1
R7 | 39k 1% | Resistor_SMD:R_0603_1608Metric |  | 1
R8 | 18k 1% | Resistor_SMD:R_0603_1608Metric |  | 1
R9 | 100k | Resistor_SMD:R_0603_1608Metric |  | 1
U1 | MCP73831T-2ACI/OT | Package_TO_SOT_SMD:SOT-23-5 | MCP73831T-2ACI/OT | 1
U2 | LM393 | Package_SO:SOIC-8_3.9x4.9mm_P1.27mm |  | 1

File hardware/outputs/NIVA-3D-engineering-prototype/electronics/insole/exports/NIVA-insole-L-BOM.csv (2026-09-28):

Reference | Value | Footprint | MPN | QUANTITY
FSR1 | P1 Big toe (shunt FSR, 12 mm) | NIVA_insole:FSR_Interdigitated_D12mm |  | 1
FSR2 | P2 Medial forefoot (shunt FSR, 12 mm) | NIVA_insole:FSR_Interdigitated_D12mm |  | 1
FSR3 | P3 Lateral forefoot (shunt FSR, 12 mm) | NIVA_insole:FSR_Interdigitated_D12mm |  | 1
FSR4 | P4 Lateral midfoot (shunt FSR, 12 mm) | NIVA_insole:FSR_Interdigitated_D12mm |  | 1
FSR5 | P5 Heel (shunt FSR, 12 mm) | NIVA_insole:FSR_Interdigitated_D12mm |  | 1
J1 | CABLE TO POD J1 (JST GH 10) | NIVA_insole:WirePads_1x10_P2.0mm_LaneOrder |  | 1
J2 | V1 PVDF FILM (signal, return) | NIVA_insole:PVDF_BondPads_2x6x2mm |  | 1
R1 | 47k 0.1% | Resistor_SMD:R_0603_1608Metric | 0603 thin film 47k 0.1% (left medium code) | 1

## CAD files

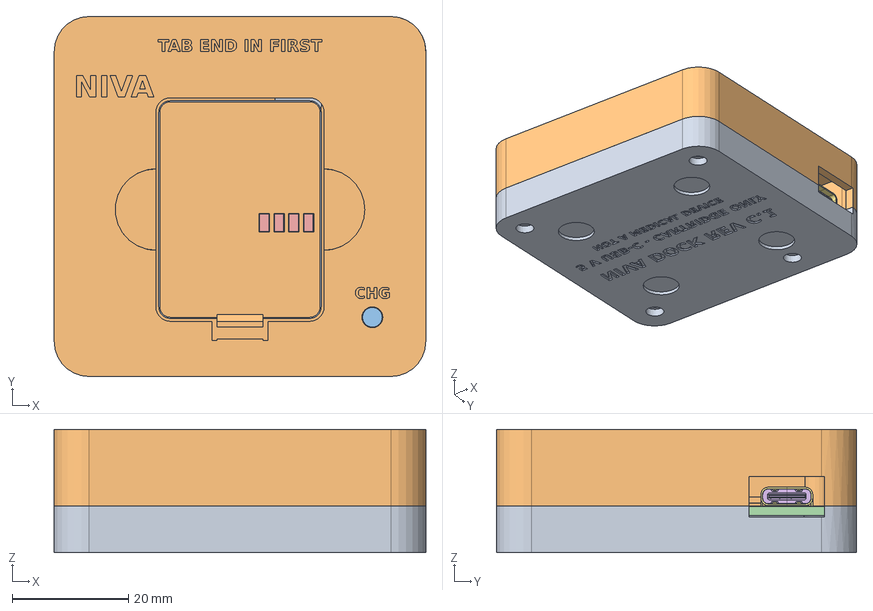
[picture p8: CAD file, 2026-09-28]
hardware/outputs/NIVA-3D-engineering-prototype/mechanical/NIVA-dock-assembly.step
64.0 x 62.0 x 21.2 mm

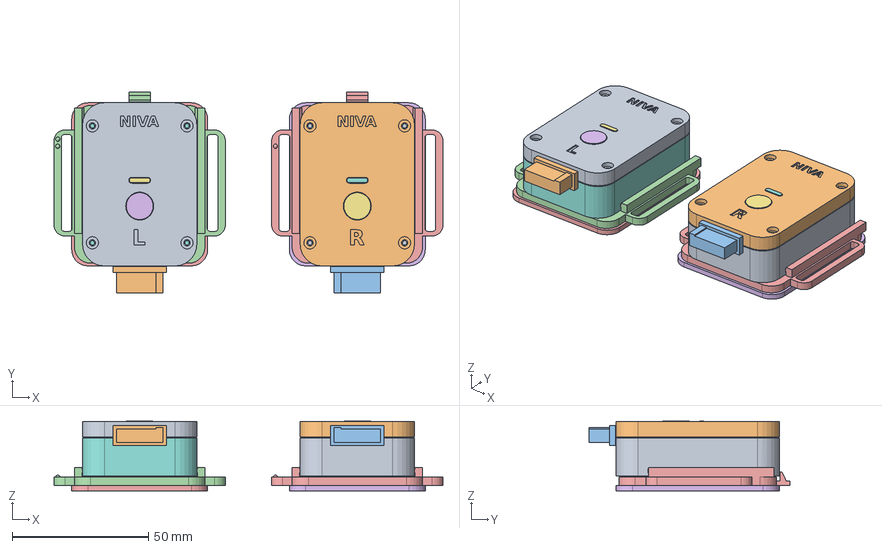
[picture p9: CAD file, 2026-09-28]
hardware/outputs/NIVA-3D-engineering-prototype/mechanical/NIVA-RevC-assembly.FCStd
143.0 x 74.0 x 25.6 mm
01_RearHousing_R
02_FrontCover_R
03_BatteryCartridgeCup_R
04_BatteryCartridgeLid_R
05_Cradle_R
06_SoftCradlePad_TPU_R
07_Button_TPU_R
08_LightWindow_Clear_R
09_SeamGasket_TPU_R
PCB_Substrate_R
TailBoot_R
ContactPlates_R
Cell_LP502030_MAXSIZE_R
CartridgeStripPCB_R
PCB_Components_KiCad_R
01_RearHousing_L
02_FrontCover_L
03_BatteryCartridgeCup_L
04_BatteryCartridgeLid_L
05_Cradle_L
06_SoftCradlePad_TPU_L
07_Button_TPU_L
08_LightWindow_Clear_L
09_SeamGasket_TPU_L
PCB_Substrate_L
TailBoot_L
ContactPlates_L
Cell_LP502030_MAXSIZE_L
CartridgeStripPCB_L
PCB_Components_KiCad_L

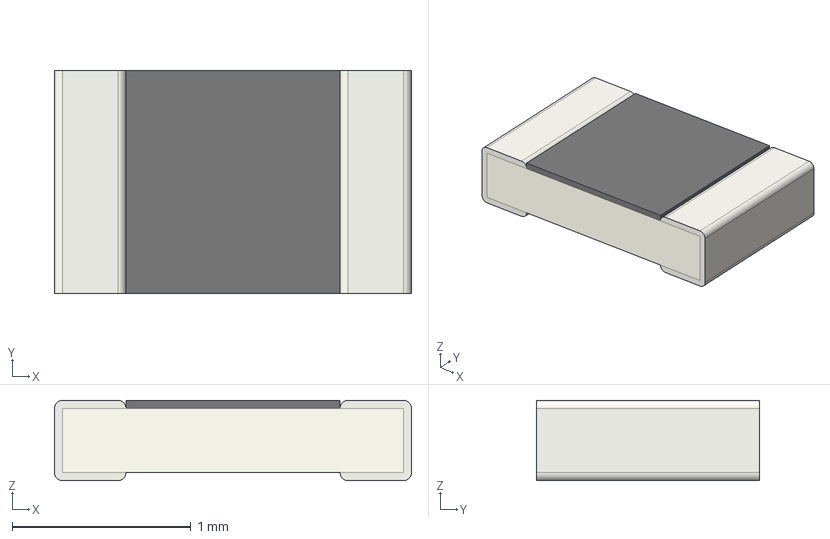
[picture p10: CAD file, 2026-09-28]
hardware/outputs/NIVA-3D-engineering-prototype/electronics/3dmodels/Fuse_0805_2012Metric.step
2.00 x 1.25 x 0.45 mm

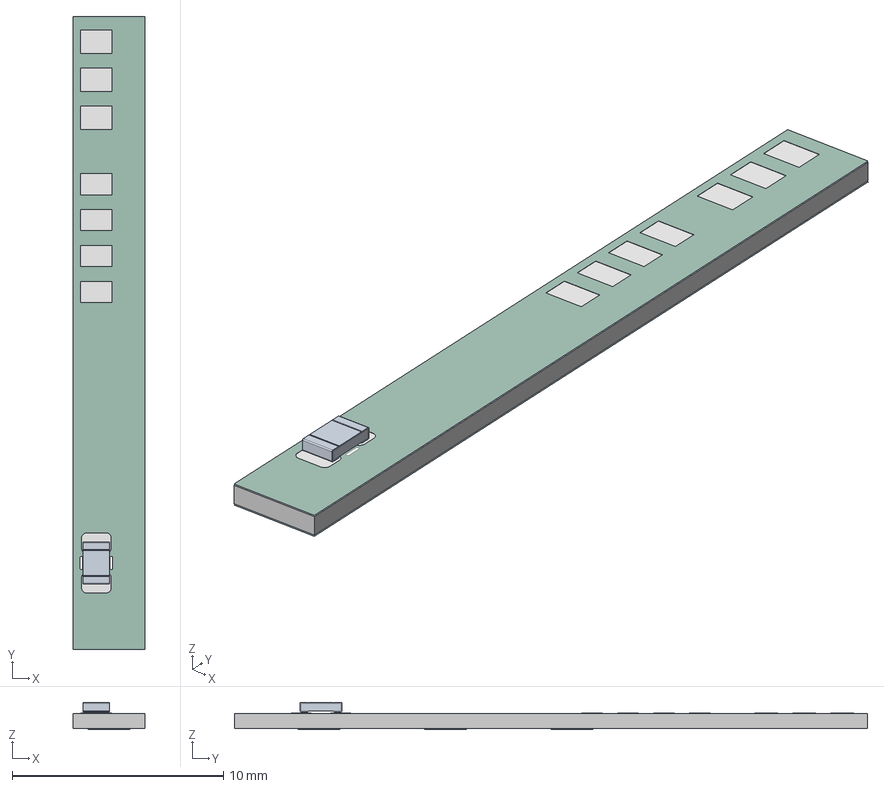
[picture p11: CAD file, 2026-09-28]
hardware/outputs/NIVA-3D-engineering-prototype/electronics/cartridge/exports/pcb/NIVA-cartridge-PCBA.step
3.40 x 30.0 x 1.30 mm
Fuse_0805_2012Metric
NIVA-cartridge_pad
NIVA-cartridge_silkscreen
NIVA-cartridge_soldermask x 2
NIVA-cartridge_PCB

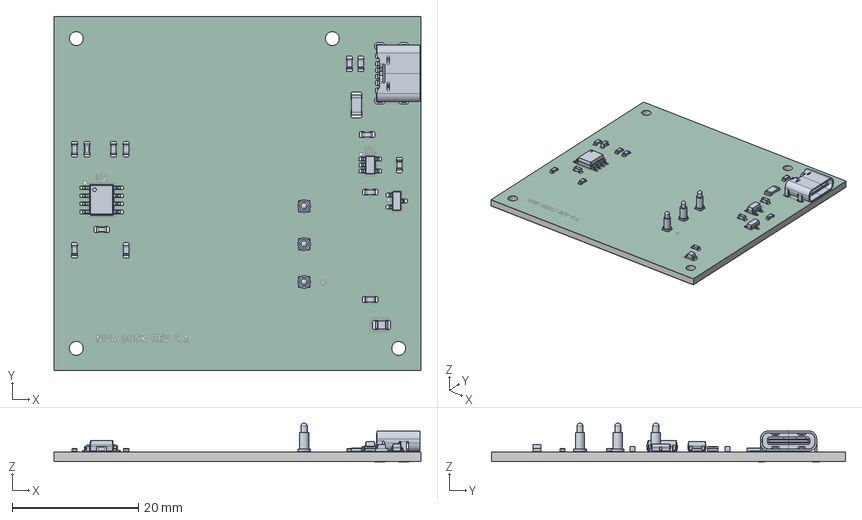
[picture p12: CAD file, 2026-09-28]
hardware/outputs/NIVA-3D-engineering-prototype/electronics/dock/exports/pcb/NIVA-dock-PCBA.step
58.0 x 56.0 x 6.14 mm
C_0603_1608Metric x 4
R_0603_1608Metric x 9
NIVA_SpringPin_1x03_ENVELOPE
Fuse_1206_3216Metric
USB_C_Receptacle_GCT_USB4125-xx-x_6P_TopMnt_Horizontal
SOT-23
LED_0805_2012Metric
SOIC-8_3.9x4.9mm_P1.27mm
SOT-23-5
NIVA-dock_pad
NIVA-dock_silkscreen
NIVA-dock_soldermask x 2
NIVA-dock_PCB

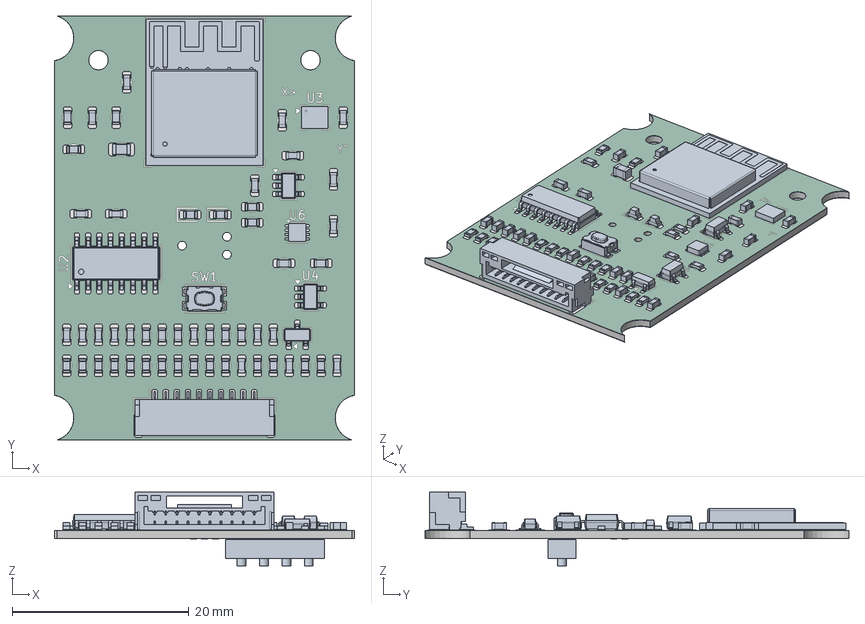
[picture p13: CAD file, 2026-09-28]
hardware/outputs/NIVA-3D-engineering-prototype/electronics/exports/pcb/NIVA-pod-PCBA.step
34.0 x 48.0 x 8.32 mm
R_0603_1608Metric x 28
C_0603_1608Metric x 21
JST_GH_SM10B-GHS-TB_1x10-1MP_P1.25mm_Horizontal
SOIC-16_3.9x9.9mm_P1.27mm
C_0805_2012Metric
SOT-23-5 x 2
TDFN-8-2x2mm_ENVELOPE
LGA-14_3x2.5mm_P0.5mm_LayoutBorder3x4y
LED_0603_1608Metric x 2
SOT-23
DFN1006.STEP^DFN1006.STEP_Submodel-SOD882_part_DesignRootModel_PCB_ ESP32-C3-MINI-1_V1(2)_PCB_ESP32-C3-MINI-1_V1
R0201_20210301.STEP^R0201_20210301.STEP_Submodel-R0201_part_ DesignRootModel_PCB_ESP32-C3-MINI-1_V1(2)_PCB_ESP32-C3-MINI-1_V1 x 3
placementOutline^Submodel-noModelForPart_MINI-ANT-TYPED-H_1968823293_ Submodel-MINI-ANT-TYPED-H_1968823293_part_DesignRootModel_PCB_ ESP32-C3-MINI-1_V1(2)_PCB_E
placementOutline-0^Submodel-noModelForPart_MINI-ANT-TYPED-H_1968823293_ Submodel-MINI-ANT-TYPED-H_1968823293_part_DesignRootModel_PCB_ ESP32-C3-MINI-1_V1(2)_PCB
placementOutline-1^Submodel-noModelForPart_MINI-ANT-TYPED-H_1968823293_ Submodel-MINI-ANT-TYPED-H_1968823293_part_DesignRootModel_PCB_ ESP32-C3-MINI-1_V1(2)_PCB
placementOutline-2^Submodel-noModelForPart_MINI-ANT-TYPED-H_1968823293_ Submodel-MINI-ANT-TYPED-H_1968823293_part_DesignRootModel_PCB_ ESP32-C3-MINI-1_V1(2)_PCB
placementOutline-3^Submodel-noModelForPart_MINI-ANT-TYPED-H_1968823293_ Submodel-MINI-ANT-TYPED-H_1968823293_part_DesignRootModel_PCB_ ESP32-C3-MINI-1_V1(2)_PCB
placementOutline-4^Submodel-noModelForPart_MINI-ANT-TYPED-H_1968823293_ Submodel-MINI-ANT-TYPED-H_1968823293_part_DesignRootModel_PCB_ ESP32-C3-MINI-1_V1(2)_PCB
placementOutline-5^Submodel-noModelForPart_MINI-ANT-TYPED-H_1968823293_ Submodel-MINI-ANT-TYPED-H_1968823293_part_DesignRootModel_PCB_ ESP32-C3-MINI-1_V1(2)_PCB
trace_4^Submodel-MINI-ANT-TYPED-H_1968823293_part_DesignRootModel_PCB_ ESP32-C3-MINI-1_V1(2)_PCB_ESP32-C3-MINI-1_V1
trace_1^Submodel-MINI-ANT-TYPED-H_1968823293_part_DesignRootModel_PCB_ ESP32-C3-MINI-1_V1(2)_PCB_ESP32-C3-MINI-1_V1
C0402_20210301.STEP^C0402_20210301.STEP_Submodel-C0402_part_ DesignRootModel_PCB_ESP32-C3-MINI-1_V1(2)_PCB_ESP32-C3-MINI-1_V1
C0201_20210301.STEP^C0201_20210301.STEP_Submodel-C0201_part_ DesignRootModel_PCB_ESP32-C3-MINI-1_V1(2)_PCB_ESP32-C3-MINI-1_V1 x 11
L0201_20210301.STEP^L0201_20210301.STEP_Submodel-L0201_part_ DesignRootModel_PCB_ESP32-C3-MINI-1_V1(2)_PCB_ESP32-C3-MINI-1_V1 x 2
XTAL3225_20210301.STEP^XTAL3225_20210301.STEP_Submodel-XTAL3225_part_ DesignRootModel_PCB_ESP32-C3-MINI-1_V1(2)_PCB_ESP32-C3-MINI-1_V1
ESP32-C3_20210301.STEP^ESP32-C3_20210301.STEP_Submodel-QFN32_0P5_5_ part_DesignRootModel_PCB_ESP32-C3-MINI-1_V1(2)_PCB_ESP32-C3-MINI-1_V1
uid__4^DesignRootModel_PCB_ESP32-C3-MINI-1_V1(2)_PCB_ESP32-C3-MINI-1_ V1
uid__4-22^DesignRootModel_PCB_ESP32-C3-MINI-1_V1(2)_PCB_ ESP32-C3-MINI-1_V1
uid__4-23^DesignRootModel_PCB_ESP32-C3-MINI-1_V1(2)_PCB_ ESP32-C3-MINI-1_V1
uid__4-24^DesignRootModel_PCB_ESP32-C3-MINI-1_V1(2)_PCB_ ESP32-C3-MINI-1_V1
uid__4-25^DesignRootModel_PCB_ESP32-C3-MINI-1_V1(2)_PCB_ ESP32-C3-MINI-1_V1
uid__4-26^DesignRootModel_PCB_ESP32-C3-MINI-1_V1(2)_PCB_ ESP32-C3-MINI-1_V1
uid__4-27^DesignRootModel_PCB_ESP32-C3-MINI-1_V1(2)_PCB_ ESP32-C3-MINI-1_V1
uid__4-28^DesignRootModel_PCB_ESP32-C3-MINI-1_V1(2)_PCB_ ESP32-C3-MINI-1_V1
uid__4-29^DesignRootModel_PCB_ESP32-C3-MINI-1_V1(2)_PCB_ ESP32-C3-MINI-1_V1
uid__4-30^DesignRootModel_PCB_ESP32-C3-MINI-1_V1(2)_PCB_ ESP32-C3-MINI-1_V1
uid__4-31^DesignRootModel_PCB_ESP32-C3-MINI-1_V1(2)_PCB_ ESP32-C3-MINI-1_V1
uid__4-32^DesignRootModel_PCB_ESP32-C3-MINI-1_V1(2)_PCB_ ESP32-C3-MINI-1_V1
uid__4-33^DesignRootModel_PCB_ESP32-C3-MINI-1_V1(2)_PCB_ ESP32-C3-MINI-1_V1
uid__4-34^DesignRootModel_PCB_ESP32-C3-MINI-1_V1(2)_PCB_ ESP32-C3-MINI-1_V1
uid__4-35^DesignRootModel_PCB_ESP32-C3-MINI-1_V1(2)_PCB_ ESP32-C3-MINI-1_V1
uid__4-36^DesignRootModel_PCB_ESP32-C3-MINI-1_V1(2)_PCB_ ESP32-C3-MINI-1_V1
uid__4-37^DesignRootModel_PCB_ESP32-C3-MINI-1_V1(2)_PCB_ ESP32-C3-MINI-1_V1
uid__4-38^DesignRootModel_PCB_ESP32-C3-MINI-1_V1(2)_PCB_ ESP32-C3-MINI-1_V1
uid__4-39^DesignRootModel_PCB_ESP32-C3-MINI-1_V1(2)_PCB_ ESP32-C3-MINI-1_V1
uid__4-40^DesignRootModel_PCB_ESP32-C3-MINI-1_V1(2)_PCB_ ESP32-C3-MINI-1_V1
uid__4-41^DesignRootModel_PCB_ESP32-C3-MINI-1_V1(2)_PCB_ ESP32-C3-MINI-1_V1
uid__4-42^DesignRootModel_PCB_ESP32-C3-MINI-1_V1(2)_PCB_ ESP32-C3-MINI-1_V1
uid__4-43^DesignRootModel_PCB_ESP32-C3-MINI-1_V1(2)_PCB_ ESP32-C3-MINI-1_V1
uid__4-44^DesignRootModel_PCB_ESP32-C3-MINI-1_V1(2)_PCB_ ESP32-C3-MINI-1_V1
uid__4-45^DesignRootModel_PCB_ESP32-C3-MINI-1_V1(2)_PCB_ ESP32-C3-MINI-1_V1
uid__4-46^DesignRootModel_PCB_ESP32-C3-MINI-1_V1(2)_PCB_ ESP32-C3-MINI-1_V1
uid__4-47^DesignRootModel_PCB_ESP32-C3-MINI-1_V1(2)_PCB_ ESP32-C3-MINI-1_V1
uid__4-48^DesignRootModel_PCB_ESP32-C3-MINI-1_V1(2)_PCB_ ESP32-C3-MINI-1_V1
uid__4-49^DesignRootModel_PCB_ESP32-C3-MINI-1_V1(2)_PCB_ ESP32-C3-MINI-1_V1
uid__4-50^DesignRootModel_PCB_ESP32-C3-MINI-1_V1(2)_PCB_ ESP32-C3-MINI-1_V1
uid__4-51^DesignRootModel_PCB_ESP32-C3-MINI-1_V1(2)_PCB_ ESP32-C3-MINI-1_V1
uid__4-52^DesignRootModel_PCB_ESP32-C3-MINI-1_V1(2)_PCB_ ESP32-C3-MINI-1_V1
uid__4-53^DesignRootModel_PCB_ESP32-C3-MINI-1_V1(2)_PCB_ ESP32-C3-MINI-1_V1
uid__4-54^DesignRootModel_PCB_ESP32-C3-MINI-1_V1(2)_PCB_ ESP32-C3-MINI-1_V1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

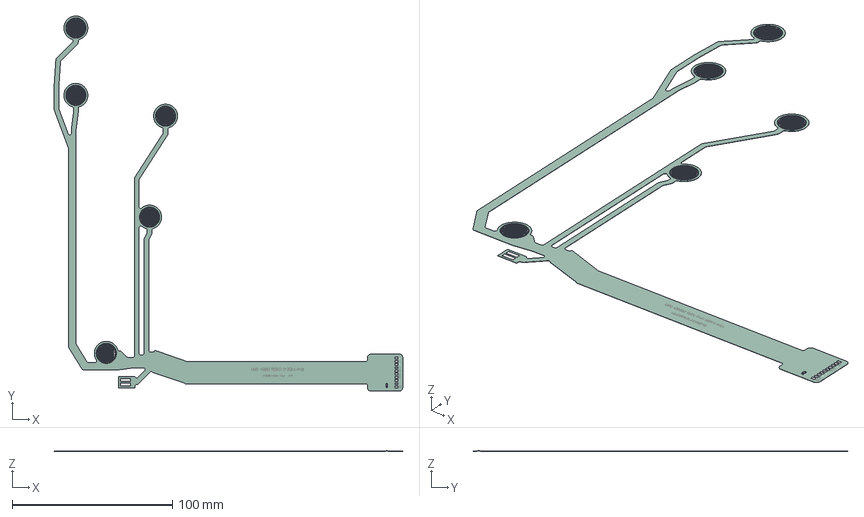
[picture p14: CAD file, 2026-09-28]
hardware/outputs/NIVA-3D-engineering-prototype/electronics/insole/exports/pcb/NIVA-insole-R-PCBA.step
217.5 x 234.0 x 0.615 mm
R_0603_1608Metric
NIVA-insole-R_pad
NIVA-insole-R_silkscreen
NIVA-insole-R_soldermask x 2
NIVA-insole-R_PCB

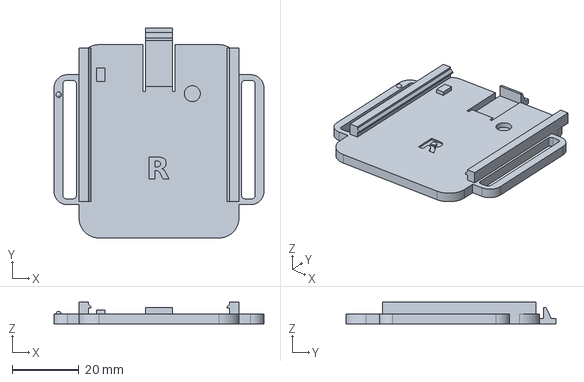
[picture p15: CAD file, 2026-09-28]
hardware/outputs/NIVA-3D-engineering-prototype/mechanical/STEP-parts/05_Cradle_R.step
63.0 x 63.0 x 6.60 mm

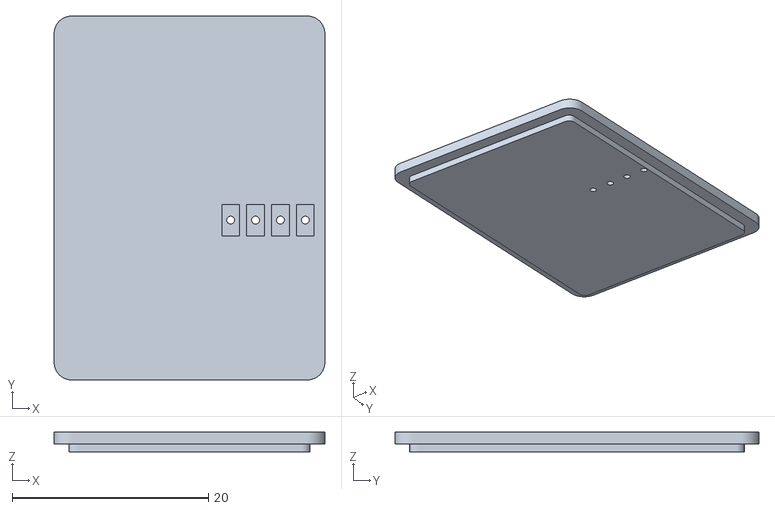
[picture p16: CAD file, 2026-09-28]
hardware/work/niva-meshes/04_BatteryCartridgeLid_R.stl
27.6 x 37.1 x 2.00

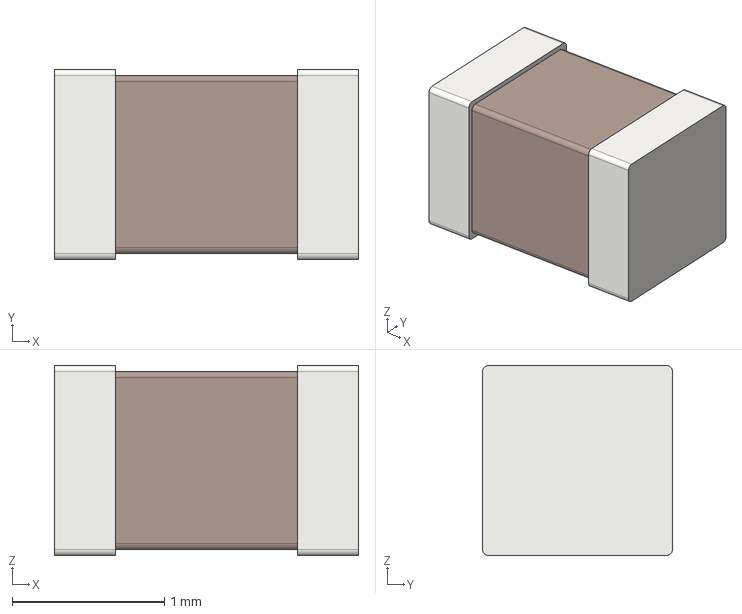
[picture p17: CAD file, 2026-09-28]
hardware/outputs/NIVA-3D-engineering-prototype/electronics/3dmodels/C_0805_2012Metric.step
2.00 x 1.25 x 1.25 mm

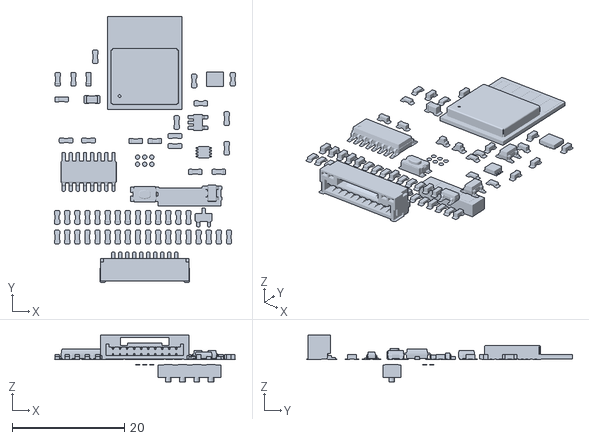
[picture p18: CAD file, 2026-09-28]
hardware/work/niva-meshes/PCB_Components_KiCad_R.stl
32.2 x 47.4 x 8.33

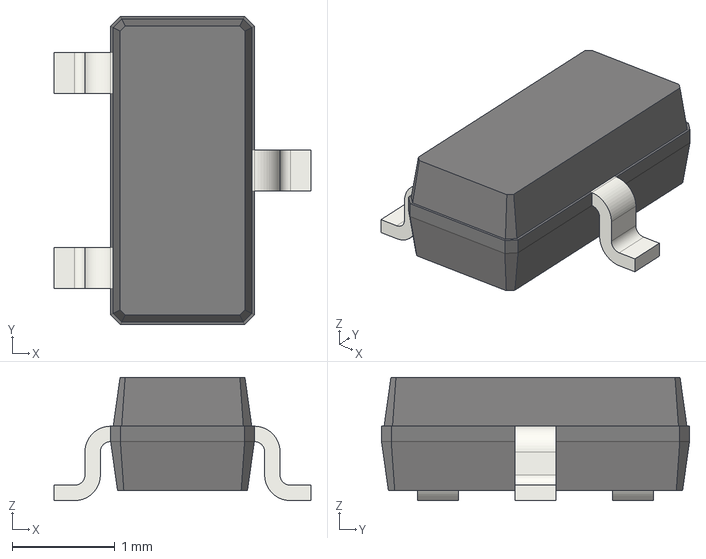
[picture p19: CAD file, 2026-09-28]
hardware/outputs/NIVA-3D-engineering-prototype/electronics/3dmodels/SOT-23.step
2.50 x 3.00 x 1.20 mm

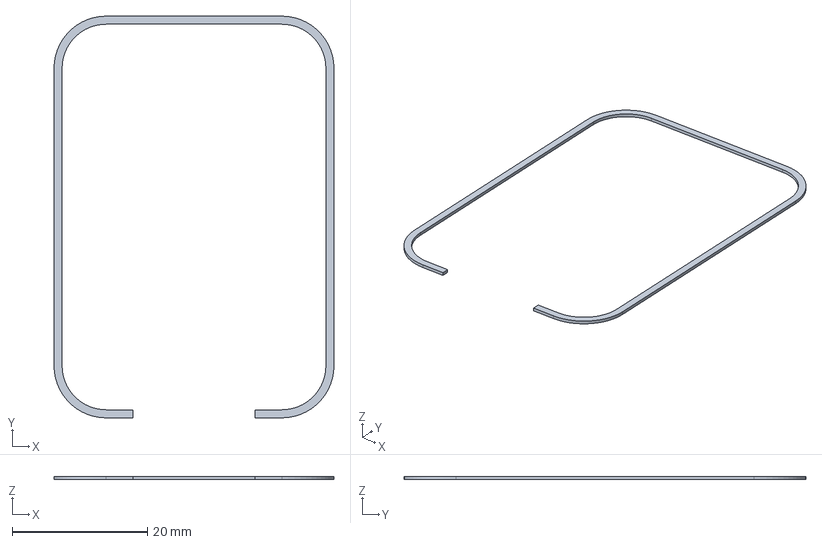
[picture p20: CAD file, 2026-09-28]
hardware/outputs/NIVA-3D-engineering-prototype/mechanical/STEP-parts/09_SeamGasket_TPU.step
41.4 x 59.4 x 0.5 mm

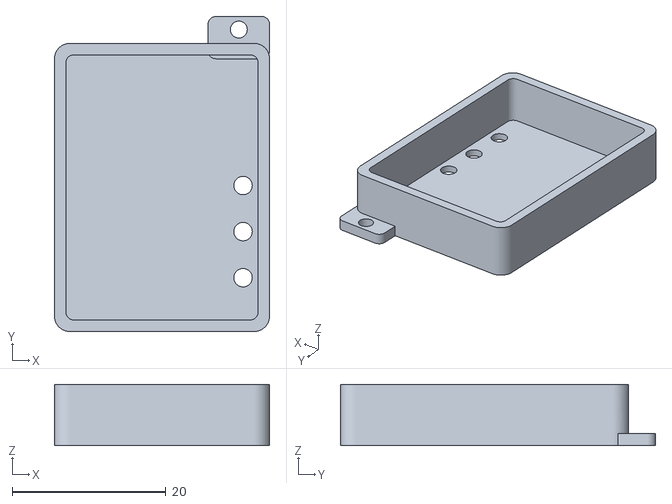
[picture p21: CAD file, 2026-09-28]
hardware/work/niva-meshes/Cartridge_Cup.stl
28.0 x 41.0 x 8.00

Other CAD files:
hardware/outputs/NIVA-3D-engineering-prototype/electronics/insole/exports/pcb/NIVA-insole-L-PCBA.step
hardware/outputs/NIVA-3D-engineering-prototype/mechanical/STEP-parts/04_BatteryCartridgeLid.step
hardware/outputs/NIVA-3D-engineering-prototype/electronics/3dmodels/R_0603_1608Metric.step
hardware/outputs/NIVA-3D-engineering-prototype/mechanical/STEP-parts/05_Cradle_L.step
hardware/outputs/NIVA-3D-engineering-prototype/blender/NIVA-RevC-scenes.blend
hardware/outputs/NIVA-3D-engineering-prototype/electronics/3dmodels/C_0603_1608Metric.step
hardware/outputs/NIVA-3D-engineering-prototype/electronics/3dmodels/D_SOD-323.step
hardware/outputs/NIVA-3D-engineering-prototype/electronics/3dmodels/ESP32-C3-MINI-1_Espressif.step
hardware/outputs/NIVA-3D-engineering-prototype/electronics/3dmodels/Fuse_1206_3216Metric.step
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

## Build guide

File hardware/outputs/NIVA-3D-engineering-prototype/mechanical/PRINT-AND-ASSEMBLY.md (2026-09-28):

# NIVA pod Rev C and charging dock Rev C.1 — printing, fasteners, clearances and assembly

Engineering prototype for fit and handling trials. **Not a released medical device**. Watertight meshes and a clean CAD interference check do not establish manufacturability, sealing or wearable safety.

Units: mm. Pod frame: x = width (0–42), y = height (0 = cable end, 60 = top), z = depth (0 = back against the cradle, 20 = front face). Left-side parts are identical to right-side parts except for keys and markings; the assembly shows the left pod 80 mm to the left of the right pod.
Dock frame: x 0–64, y 0–62, z up from the desk. It is the pod frame shifted by (11, 5) mm, so the cartridge's dock pads and the dock's spring pins share x/y without mirroring. The dock is a separate assembly: `NIVA-dock-assembly.FCStd` / `.step`.

## 1. Printable parts

The STLs in `STL-print-parts/` are **already rotated into the recommended print orientation** and sit on z = 0. The STEPs in `STEP-parts/` are in the assembly (pod) frame.

| File | Material | Rigid / flexible | Recommended orientation | Notes |
|---|---|---|---|---|
| `01_RearHousing_R/L` | PETG or ASA, navy | rigid | rear face on bed (as modelled); no supports | The ledge gussets and groove chamfers are 45° self-supporting. The bay ceiling bridges 28.8 mm (check bridging). Use ≥ 4 perimeters around the screw pilots. |
| `02_FrontCover_R/L` | PETG or ASA, pale grey-blue | rigid | cosmetic face on bed (flipped); no supports | The debossed NIVA and R/L marks print on the bed face. |
| `03_BatteryCartridgeCup` | PETG, navy | rigid | rear face on bed; no supports | Printed cups are for fit trials with an **inert dummy cell block**. A live-cell cartridge needs the moulded, welded cup and the checks in `../VERIFICATION-PLAN.md`. Three Ø2.4 windows in the floor expose the strip PCB's dock pads. |
| `04_BatteryCartridgeLid` | PETG, navy | rigid | contact face on bed (flipped); no supports | Has four contact-plate pockets. Bond it to the cup; a live-cell cartridge must not be user-openable. |
| `05_Cradle_R/L` | PETG, navy | rigid | back (leg side) on bed; no supports | The latch arm is thinned from the top so it prints flat. PLA is not recommended for the latch (creep). |
| `06_SoftCradlePad_TPU` | TPU 85A–95A, teal | flexible | flat | Skin contact: material suitability not assessed. |
| `07_Button_TPU` | TPU 85A–95A, teal | flexible | crown on bed (flipped) | The flange overhangs 1.5 mm; add support if your profile needs it. Moulded silicone is the production intent. |
| `08_LightWindow_Clear` | clear SLA resin (preferred) or clear PETG | rigid | window face on bed (flipped) | The flange needs support in FDM. |
| `09_SeamGasket_TPU` | 0.5 mm silicone/EPDM sheet, **die-cut** (TPU print for fit trial only) | flexible | flat | 0.5 mm free thickness, 0.35 mm installed. |
| `10_DockBase` | PETG, navy | rigid | bottom on bed; no supports | Four M2 standoffs with counterbored screw entries from below, 8 mm bumper recesses, debossed label (reads correctly from below). |
| `11_DockTop` | PETG, pale grey-blue | rigid | top face on bed (flipped); no supports | The well floor is a 29 mm bridge in this orientation: enable bridging. Keyed well, tab slot under the far ledge, cantilever snap latch (8 × 1.0 × 10.4 mm arm), finger notches, spring-pin holes, USB-C opening, light-pipe tube. |
| `12_DockLightPipe_Clear` | clear SLA resin or clear PETG | rigid | flange on bed (flipped) | Ø2.3 rod, 0.25 mm above the amber charge LED. |

`geometry-validation.json` (pod) and `dock-geometry-validation.json` (dock) record for every part: one valid solid, closed mesh, no non-manifold edges, volume and print bounding box.

## 2. Bought-in parts per pod

| Qty | Item | Where | Notes |
|---|---|---|---|
| 4 | M2 × 10 pan head, thread-forming for plastics (head Ø4.0 × 1.6, DIN 7985 / ISO 7045 style) | front cover → rear housing | 1.6 mm pilot, about 6 mm engagement, Ø4.5 × 1.7 counterbore. |
| 2 | M2 × 5 pan head, thread-forming | PCB (H1, H2) → rear housing bosses | 1.6 mm pilot, 6.8 mm deep. |
| 1 | M2 × 6 pan head, thread-forming | cartridge tab → rear screw post | Hidden by the cradle when worn: this is the charging-exclusion feature. |
| 4 | Brass contact plate 1.6 × 3.0 × 0.4, gold flash (to select) | cartridge lid pockets | Wired to the strip PCB's J2 pads (2 × P−, 2 × P+) through Ø0.8 holes. |
| 1 | Cell: EEMB LP502030 class with protection module and NTC lead (230 mAh min / 250 mAh typ, 20.5 × 32 × 5.3 mm max) | cartridge cup | The part class is selected, not a purchased lot. Confirm the lot datasheet and the NTC value before use. |
| 1 | Cartridge strip PCB (`../electronics/cartridge`), 3.4 × 30 × 0.8 mm, with an 0805 polyfuse | cartridge cup floor, beside the cell | Its gold dock pads face the floor windows. |
| 1 | Pod PCBA (see `../electronics`) | — | A routed prototype that passes KiCad ERC and DRC. It is **not reviewed or released** for fabrication. |
| 1 | Insert (sensing flex laminated inside, `../electronics/insole`) with cable and overmoulded, keyed JST GH 10 boot | J1 | The boot is modelled as `TailBoot_R/L` (not printed). |
| 1 | 35 mm smooth silicone ladder strap | cradle slots | Not modelled in CAD; shown in the renders. |

**Per dock:** 4 × M2 × 12 pan head, thread-forming (base → PCB → top bosses; 1.7 mm pilots, about 5.8 mm engagement); 4 × Ø8 × 2 mm adhesive bumpers; 1 dock PCBA (`../electronics/dock`, spring pins **not selected**); a USB-C 5 V supply and cable.

**Torque:** not specified. Thread-forming M2 in PETG strips easily. Start at about 0.1 N·m, set the value by test, and expect a limited number of service cycles. Heat-set inserts do not fit the 4.4 mm bosses.

## 3. Nominal clearances

These are measured in the Rev C CAD (`interference-report.json`) against the real KiCad PCBA model.

| Interface | Nominal |
|---|---|
| Cartridge cup in bay pocket | 0.4 per side |
| Cartridge lid to bay ceiling | ≥ 0.6 |
| Spring plungers to lid plates | **0.4 preload** (the only intended overlap in the audit) |
| Front-cover locating lip in rear cavity | 0.2 per side |
| Gasket | 0.5 free → 0.35 installed (30 % compression), set by boss-to-boss hard stops at z = 14.35 |
| Cradle rail lips in housing grooves | 0.2 on each face; cradle plate to pod back 0.4 |
| Latch hook to pod top face | 0.3; key post in key slot 0.2 (depth) |
| Button crown in Ø10.3 hole | 0.2 radial; plunger to KMR2 switch 0.2 pre-travel |
| Light pipe in window | 0.2 per side; 0.3 above the emitters |
| PCB components to front cover / rear housing | min 1.16 (J1) / 0.6 |
| Tail boot in aperture | 0.2; boot to J1 face 0.4 |
| PCB notches to enclosure bosses | 0.4 |
| PCB on ledges and clamp ribs | 0 nominal. Board thickness tolerance (±0.1) is not yet absorbed: tune the rib height. |
| Cell (published maximum size) in the cartridge | 0.9 to the lid plug; 0.55 to the strip PCB (`interference-report.json`) |
| Cartridge in the dock well | 0.5 per side; tab in its slot 0.5 per side, 0.2 above |
| Dock latch hook over the cartridge lid | 0.1 free play, 0.5 overlap on the lid edge |
| Dock spring pins on the cartridge pads | 0.70 compression seated, 0.60 when pushed up onto the hook (envelope pin, 4.5 mm free height) |
| Dock PCB clamp | standoff tops 0.06 below the board underside; top bosses bear on the board's top face. Tallest component to the top housing is 0.53 |

FDM accuracy is typically ±0.1–0.2 mm, so every 0.2 mm fit above must be checked on real prints.

## 4. Assembly sequence (one pod)

1. **Rear housing:** check that all pilots are clear. Optionally run each screw in once to form the threads.
2. **PCB:** lower it onto the side and bottom ledges so J2 and the service pads pass the bay-ceiling windows and the notches clear the four bosses. Fit 2 × M2 × 5 at H1/H2.
3. **Front cover sub-assembly:**
   - Push the light pipe into the window from inside and retain it with a small bead of UV adhesive on the flange.
   - Drop the TPU button into its hole from inside.
4. **Gasket:** lay it on the rear rim, clear of the bosses, with the gap at the tail aperture.
5. **Close:** fit the front cover, with the lip inside the rear cavity and the aperture halves aligned. Drive 4 × M2 × 10 in a cross pattern to the boss hard stop. Do not over-torque.
6. **Cartridge (dummy):** bond the lid to the cup with the contact plates fitted. Insert it from the rear, tab first into its recess, and fit the M2 × 6 screw.
7. **Tail:** insert the keyed boot through the aperture until the GH latch engages. The boot key tab only fits the matching side.
8. **Cradle:** bond the TPU pad under the cradle (adhesive to be chosen) and thread the strap through both slots.
9. **Mount:** slide the pod down the cradle rails, key post into the rear slot, until it stops at the groove end and the latch hook snaps over the top face. Confirm that the other side's pod cannot be inserted.
10. **Removal (for charging):** press the latch tab away from the pod, slide the pod up and off, remove the M2 × 6, and withdraw the cartridge. Charging happens only in the separate dock (§4b).

## 4a. Cartridge assembly (bench; live cells only after the verification plan's F4 items)

1. Solder the cell's +, − and NTC leads to strip PCB J1 (pads offset to −x, toward the cell).
2. Solder four leads from strip J2 to the lid plates (P−, P−, P+, P+), and fit the plates into the lid pockets.
3. Lay the strip PCB on the cup floor, gold pads down over the three windows. Seat the cell against the −x wall with its PCM at the +y end.
4. Bond (production intent: weld) the lid. The cartridge must not be user-openable.

## 4b. Dock assembly and use

1. Fit the light pipe into the top from above; its flange sits in the counterbore.
2. Place the dock PCBA on the base standoffs (USB-C toward the +x wall opening), lower the top onto it, and drive 4 × M2 × 12 up through the base.
3. Stick the bumpers into the four base recesses.
4. **Use:** tilt the bare cartridge rear face down, slide its tab into the slot under the far ledge (the top face says TAB END IN FIRST), then press the near end down until the latch clicks. Amber light = charging (MCP73831 STAT). To remove it, push the latch arm back and lift the near end using the side finger notches.

## 5. Unverified fits and safety mechanisms

- **Charging exclusion:** the pod has no port, coil or charger. The cartridge screw is hidden under the cradle, and only a bare cartridge fits the dock well (the pod is far too large for it). This is a mechanical intent; it is untested, including against deliberate defeat.
- **Battery:**
  - The cell *class* is selected: EEMB LP502030, 230 mAh minimum. The original 300 mAh target does **not** fit, and none is claimed.
  - The cartridge layout is designed around the published maximum size plus an 8 % swelling allowance.
  - Not yet done: a purchased lot, swelling under cycling, the lid welding process, and cell safety evidence (see `../VERIFICATION-PLAN.md` F4).
- **Spring contacts:** neither the pod J2 nor the dock J2 part is selected, so preload, contact resistance, wear and vibration performance are all unverified. Both 3D models are envelopes.
- **Dock:**
  - The latch strain estimate (≈ 1.7 %), the 29 mm bridged well floor and the USB-C plug overmould clearance (13 × 7 mm opening) need checking on prints.
  - The charger's NTC window thresholds are designed, not measured.
- **Sealing:** the gasket path, boot seal and button seal are not validated. **No IP rating is claimed.**
- **Screws and bosses:** strip-out, boss cracking, service life and torque are untested.
- **Cradle latch:** the hand calculation (ε ≈ 1.5·t·δ/L², t = 1.6, δ = 1.8, L ≈ 14.5) gives about 2 % peak strain, within the short-term range of PETG but with little margin. Release force, creep, fatigue, accidental release and retention under strap load are all untested; lengthen or thin the arm if prints crack.
- **L/R keys:**
  - The cradle key post (1.2 mm) and boot key tab (0.5 mm) are small and could be forced.
  - A complete matched set on the wrong leg is **not** prevented; the app's side check and fitting check remain required.
- **Button:** KMR2 travel and force through TPU, flange retention and feel are untested.
- **Light pipe:** coupling, amber mixing and light bleed are untested.
- **PCB clamping:** board thickness tolerance is not yet absorbed by the ribs.
- **Antenna:** metal screws sit 6–8 mm from the antenna region, with housing and body detuning on top. Not measured.
- **Skin contact and pressure:** TPU pad and silicone strap materials, pressure under the strap and cradle, and sweat and heat are not assessed.
- **Cleaning:** disinfectant compatibility of all printed and soft materials is untested.
- **Underfoot:**
  - The discrete-sensor tail problem (hold H1) is addressed by the integrated sensing flex in `../electronics/insole`, which has no sensor tails and uses one copper layer and no parts underfoot.
  - The flex, its FSR ink film, the lamination and the tail fold are all **untested** (verification plan S7, S8, F2, F3).
  - The CAD insole is still the passive visual insert from the 1:1 fit template.
- **Sealing, skin contact, cleaning:** see `../VERIFICATION-PLAN.md`. Nothing is claimed.

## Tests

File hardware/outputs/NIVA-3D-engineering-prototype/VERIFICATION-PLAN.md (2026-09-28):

# NIVA verification plan — sealing, skin contact, cleaning (and the checks they depend on)

**Status: plan only. None of these tests has been run.** This file names what has to be shown before anyone
can say the pod, cartridge, dock or insole is sealed, suitable for skin contact or cleanable. It makes **no**
claims of an IP rating, biocompatibility, disinfectant compatibility or durability. The acceptance criteria
below are proposed engineering targets for a prototype programme. They are not regulatory limits. If NIVA
is ever placed on the market as a medical device, a qualified regulatory and biological-safety review must
replace this plan.

Standards are named only as test **methods** to borrow. Naming a method is not a statement that the design
conforms to it.

## 1. Materials (proposed, to confirm)

| Item | Prototype material (printed or hand-made) | Candidate for skin-contact or wet trials | Contact type |
|---|---|---|---|
| Pod rear housing, front cover, cradle | PETG or ASA, FDM | Injection-moulded PC/PBT or PA12 grade with supplier ISO 10993 data | Indirect (strap and pad between) |
| Soft cradle pad | TPU 85A–95A, FDM | Medical-grade TPU or silicone (LSR) with supplier ISO 10993-5/-10/-23 data | **Prolonged skin contact** (shin) |
| Strap | Commercial 35 mm strap | Silicone or textile strap with supplier skin-contact data; latex-free | **Prolonged skin contact** |
| Seam gasket | Die-cut 0.5 mm silicone or EPDM sheet (TPU print is for fit only) | Silicone 40–50 Shore A, compression-set data at 40 °C | None (internal) |
| Button | TPU, FDM | LSR or TPU membrane moulded or bonded to the cover | Finger |
| Light window | Clear SLA resin | PC or PMMA, bonded | Finger |
| Tail boot | TPU overmould (modelled) | TPU overmould over the cable jacket | Occasional skin (ankle) |
| Cartridge cup and lid | PETG, FDM; lid bonded | PC or PC/ABS, ultrasonically welded | Handling |
| Cartridge contacts | Brass, gold flash (to select) | Gold over nickel. Nickel release is irrelevant only if the plates never touch skin (they sit inside the bay) | None when worn |
| Insole flex | Polyimide, rolled-annealed copper, coverlay, FSR ink film on a spacer | Same, laminated between a top cover and a base foam | **Prolonged skin contact through the sock** (top cover only) |
| Insole top cover | — | Moisture-wicking polyester or PU-coated textile with supplier skin-contact data | Through sock |
| Dock | PETG, FDM | PC/ABS | Handling |

Printed PETG, ASA and TPU prototypes are **not** evaluated for skin contact. For wear trials, either use
materials that have supplier biological-evaluation data, or put a barrier (sleeve or sock) between skin and
printed parts. Record lot numbers for every skin-contact material.

## 2. Sealing

What has to stay dry: the pod's inside (PCB, IMU, ADC). The cartridge bay is open by design. What is sealed
there is the cartridge itself (bonded or welded lid, flush contact plates) and the bay ceiling, which keeps
the PCB out of reach. The dock is a desk accessory and is not sealed. The insole flex is laminated. Sweat and
wash water must not reach the electrodes or the FSR film.

| # | Test | Method (borrowed) | Sample | Proposed acceptance |
|---|---|---|---|---|
| S1 | Gasket compression and stop check | Measure the installed gap at 8 points with feeler gauges or CT; check the boss hard stops touch | 5 assembled pods | Gap 0.35 ± 0.05 mm everywhere; no gasket extrusion |
| S2 | Splash, pod worn orientation | IEC 60529 IPX4 spray/splash procedure | 5 pods, cartridge in, tail boot fitted | No water inside the pod. Moisture-indicator paper inside, 0 marked spots |
| S3 | Dust (optional, outdoor use) | IEC 60529 IP5X talcum chamber | 3 pods | No talc on the PCB side |
| S4 | Artificial sweat soak of seams | Artificial sweat (ISO 3160-2 or EN 1811 recipe), 40 °C, 8 h wet / 16 h dry, 10 cycles | 5 pods | No ingress (indicator paper); gasket compression set < 25 % |
| S5 | Cartridge seal | Submerge a bare cartridge at 0.2 m for 30 min after 50 dock insertions | 5 cartridges | No water in the cup; contact resistance change < 20 mΩ |
| S6 | Tail boot and aperture | 500 flex cycles ±30° at the boot, then S2 | 5 pods | No ingress; jacket not pulled out (pull test 20 N after cycling) |
| S7 | Insole lamination | 40 °C artificial sweat, 24 h, then 10 000 heel-strike cycles (see F2) | 5 insoles per side | No delamination; FSR baseline shift < 10 % of unloaded reading |
| S8 | Insole hand wash (if offered) | 30 °C mild detergent, 5 min, air dry 24 h, 10 cycles | 5 insoles | As S7, plus no visible blistering. If it fails, the insole is "wipe only" |

**No IP code may be written on labels, the app or documents until S2 (and S3 if claimed) pass on production-intent parts.**

## 3. Skin contact

| # | Test | Method (borrowed) | Applies to | Proposed acceptance |
|---|---|---|---|---|
| B1 | Biological evaluation plan | ISO 10993-1 categorisation: surface device, intact skin, contact duration (prolonged, > 24 h cumulative, for daily wear) | Pad, strap, insole top cover, tail boot | Plan written and signed off by a qualified person before any wear trial beyond the team |
| B2 | Cytotoxicity | ISO 10993-5 | Each skin-contact material, finished state (after printing, moulding or lamination) | Supplier or lab data showing a non-cytotoxic result on the actual grade |
| B3 | Sensitisation | ISO 10993-10 | As B2 | Supplier or lab data: no sensitisation |
| B4 | Irritation | ISO 10993-23 | As B2 | Supplier or lab data: non-irritant |
| B5 | Nickel release | EN 1811 | Any metal that can touch skin (strap buckles, screws visible from the leg side) | Below the EN 1811 limit, or no skin-contact metal (preferred) |
| B6 | Pressure under cradle and strap | Thin-film pressure mapping on 10 adult shins at the recommended strap tension, 30 min seated plus 10 min walking | Pod on cradle | Record peak and mean pressure. No marks persisting > 30 min after removal. Target to be set with a clinician before trials |
| B7 | Heat and sweat | Skin temperature under the pad, 30 min walking at 22 °C | Pod | Skin temperature rise < 2 °C over contralateral (proposed) |
| B8 | Insole local pressure | Pressure mapping insole-on-insole with and without the flex, same shoe | Insole | No local pressure peak added over the lanes or tail tab. The flex must not be felt as a ridge (questionnaire) |

Wear trials with people outside the development team need ethics or institutional review as applicable.
This plan does not authorise them.

## 4. Cleaning

Candidate agents (confirm what users and clinics actually use): 70 % isopropyl alcohol wipes, quaternary
ammonium wipes, 0.1 % (1000 ppm) sodium hypochlorite, and mild soap and water.

| # | Test | Method | Sample | Proposed acceptance |
|---|---|---|---|---|
| C1 | Wipe cycles, rigid parts | 500 wipe cycles per agent, 1 min wet contact, dry, repeat. Inspect at 100, 250, 500 | Printed and production-intent coupons plus 3 pods | No crazing, cracking, tackiness or colour change beyond ΔE 3; markings still legible |
| C2 | Soft parts | As C1 on pad, strap, button, tail boot | 3 each | Shore A change < 5; no swelling > 2 % mass |
| C3 | Environmental stress cracking | Agent applied to screw bosses and the latch at assembly strain, 72 h | 3 cradles, 3 rear housings | No cracks (dye penetrant) |
| C4 | Seal after cleaning | Repeat S2 after C1 | 3 pods | As S2 |
| C5 | Insole top cover | 100 wipe cycles per agent, then S7 electrical baseline | 3 insoles | No delamination; baseline shift < 10 % |
| C6 | Dock and cartridge contacts | IPA wipe of the gold pads, 200 cycles | 3 cartridges | Contact resistance change < 20 mΩ; no exposed nickel |
| C7 | Instructions | Draft cleaning instructions from C1–C6 results only | — | Every step traceable to a passed test |

## 5. Checks the above depend on

| # | Check | Why it matters |
|---|---|---|
| F1 | Snap and latch life: cradle latch 1000 cycles, dock latch 2000 cycles, force at 0 / 500 / 1000 | Retention, cracking under cleaning agents (C3) |
| F2 | Insole flex durability: 100 000 heel-strike cycles at 1.5× body-weight pressure on P5, 10 000 90° folds at the heel tab (tail), 5 mm radius | Copper cracking; FSR drift |
| F3 | FSR characterisation: force-resistance curve, hysteresis, drift at 10 min static load, temperature 20–40 °C, per region | **No force or clinical value may be derived from the insole until this exists** |
| F4 | Cell and charger: cell supplier's IEC 62133-2 and UN 38.3 evidence for the exact part; dock charge termination at 4.20 V ± 1 %; NTC window trips measured at 0 °C and 45 °C | Battery safety. The dock's hardware NTC window is designed, not verified |
| F5 | Radio: the ESP32-C3-MINI-1 module certification covers the module only. The finished pod needs its own radiated and EMC assessment (for example ETSI EN 300 328, FCC Part 15) | Antenna next to the shin and battery |
| F6 | Insert ID: every insole reads its code (R-M 0.320, L-M 0.825 of VEXC ± 3 %). The app refuses a mismatched side | L/R safety net behind the mechanical keys |

## 6. Records

Record for each test: sample IDs, material lots, firmware version, date, operator, raw data, photos and
pass/fail against the criteria above. Do not change a criterion after seeing results without writing down
the reason.

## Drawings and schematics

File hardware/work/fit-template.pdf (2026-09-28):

## NIVA / MEDIUM FIT STUDY / 1:1

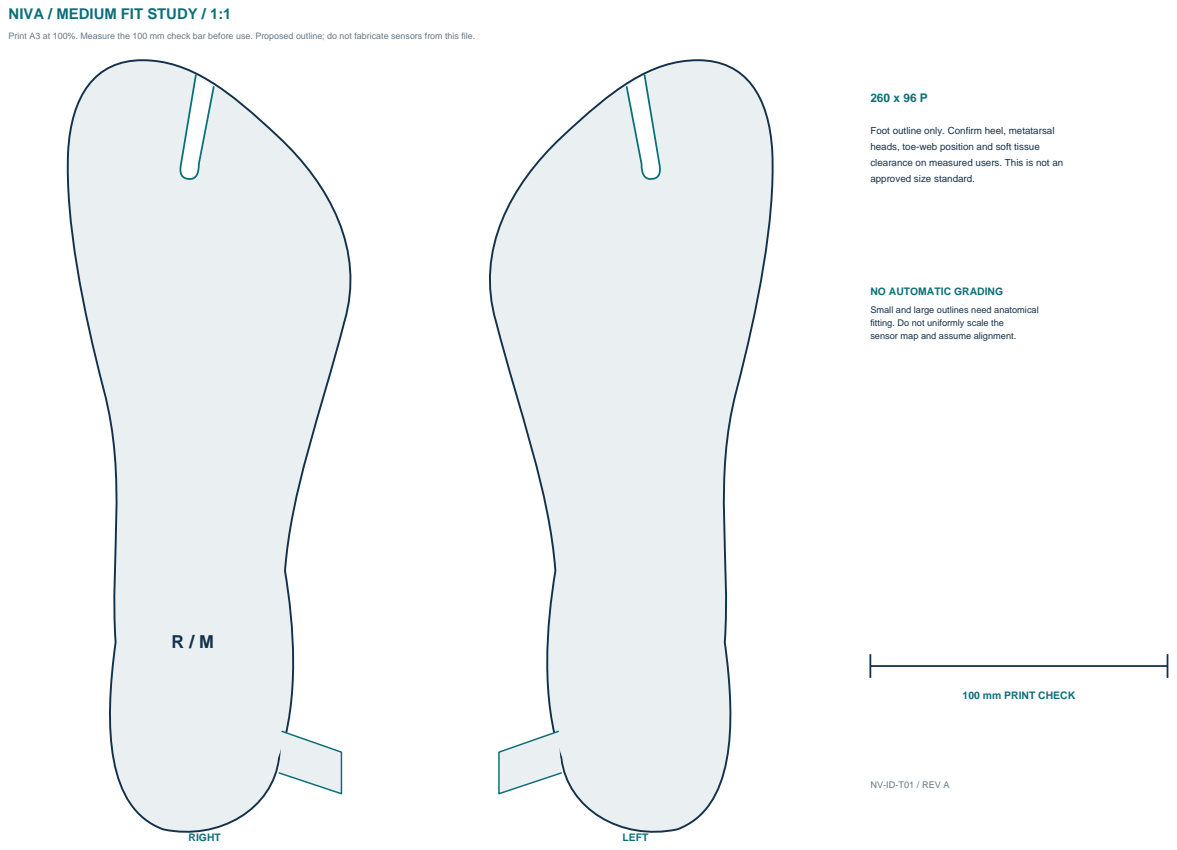
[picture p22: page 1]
RIGHT; LEFT

Print A3 at 100%. Measure the 100 mm check bar before use. Proposed outline; do not fabricate sensors from this file.

Foot outline only. Confirm heel, metatarsal
heads, toe-web position and soft tissue
clearance on measured users. This is not an
approved size standard.

NO AUTOMATIC GRADING
Small and large outlines need anatomical
fitting. Do not uniformly scale the
sensor map and assume alignment.

100 mm PRINT CHECK

NV-ID-T01 / REV A

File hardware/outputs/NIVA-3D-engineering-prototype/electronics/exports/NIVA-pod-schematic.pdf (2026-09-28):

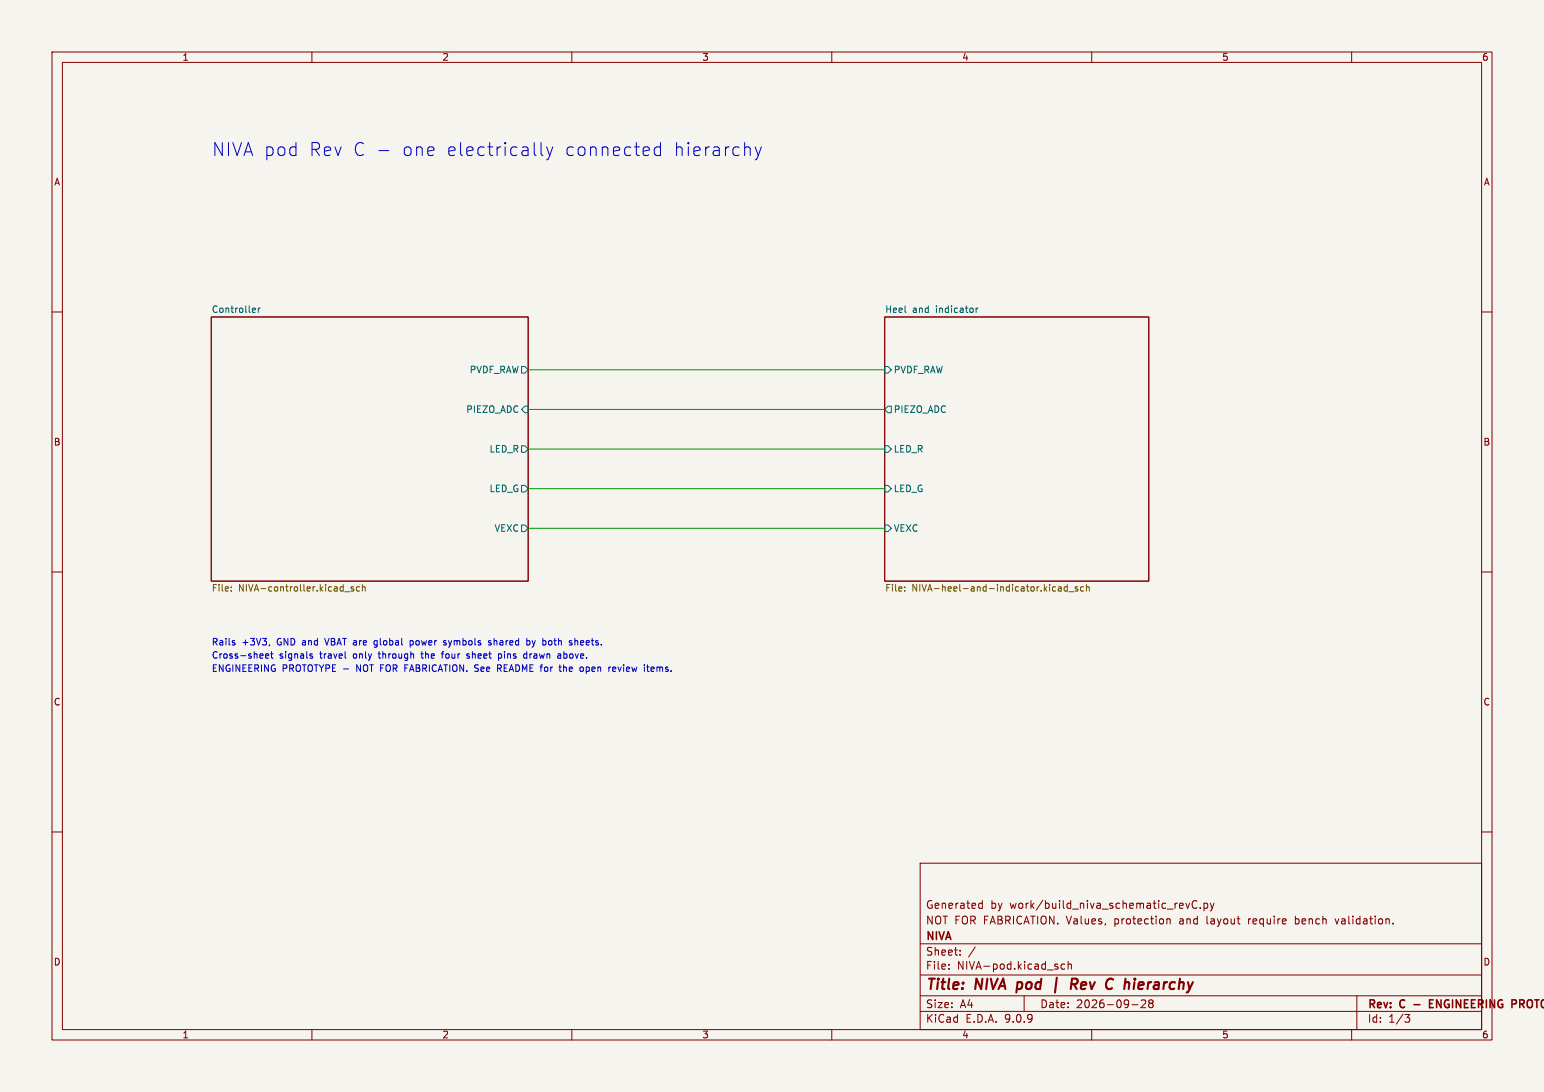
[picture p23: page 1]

Heel and indicator File: NIVA-heel-and-indicator.kicad_sch PVDF_RAW

File: NIVA-pod.kicad_sch Sheet: / NIVA

Id: 1/3 Title: NIVA pod | Rev C hierarchy

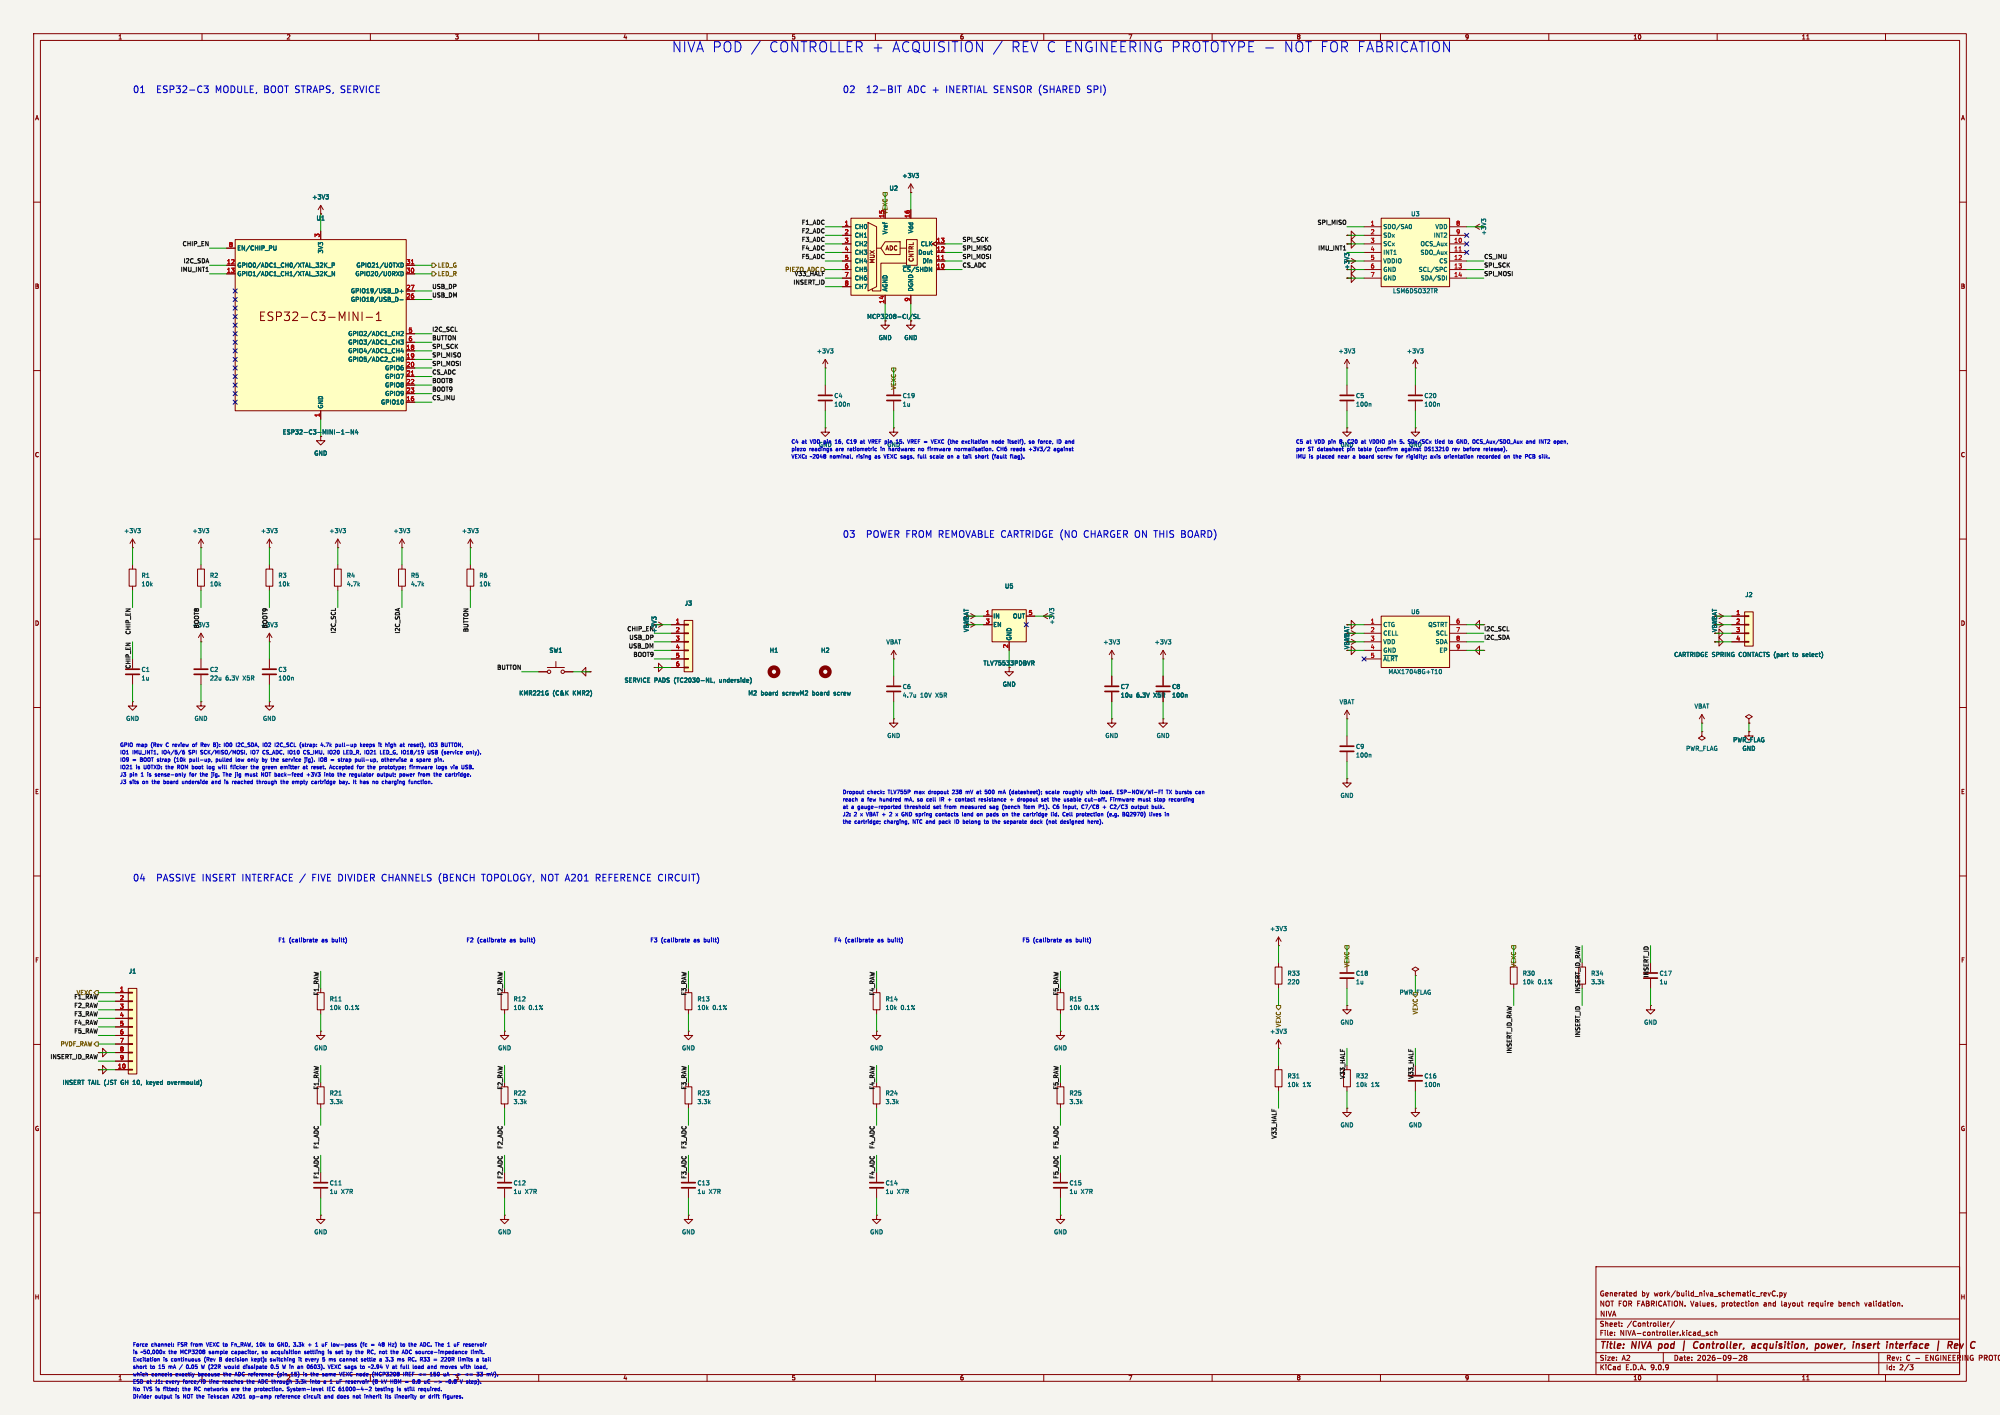
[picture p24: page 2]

NIVA POD / CONTROLLER + ACQUISITION / REV C ENGINEERING PROTOTYPE - NOT FOR FABRICATION

9 CLK 13 Dout 12 Din 11 ~{CS}/SHDN10 +3V3 +3V3 VBAT PWR_FLAG

9 CLK 13 Dout 12 Din 11 ~{CS}/SHDN10 U2 MCP3208-CI/SL +3V3 C4

J2 CARTRIDGE SPRING CONTACTS (part to select) +3V3 VEXC

C5 at VDD pin 8, C20 at VDDIO pin 5. SDx/SCx tied to GND, OCS_Aux/SDO_Aux and INT2 open,

03 POWER FROM REMOVABLE CARTRIDGE (NO CHARGER ON THIS BOARD)

J2 CARTRIDGE SPRING CONTACTS (part to select) 1

INSERT TAIL (JST GH 10, keyed overmould) 1

File: NIVA-controller.kicad_sch Sheet: /Controller/ NIVA

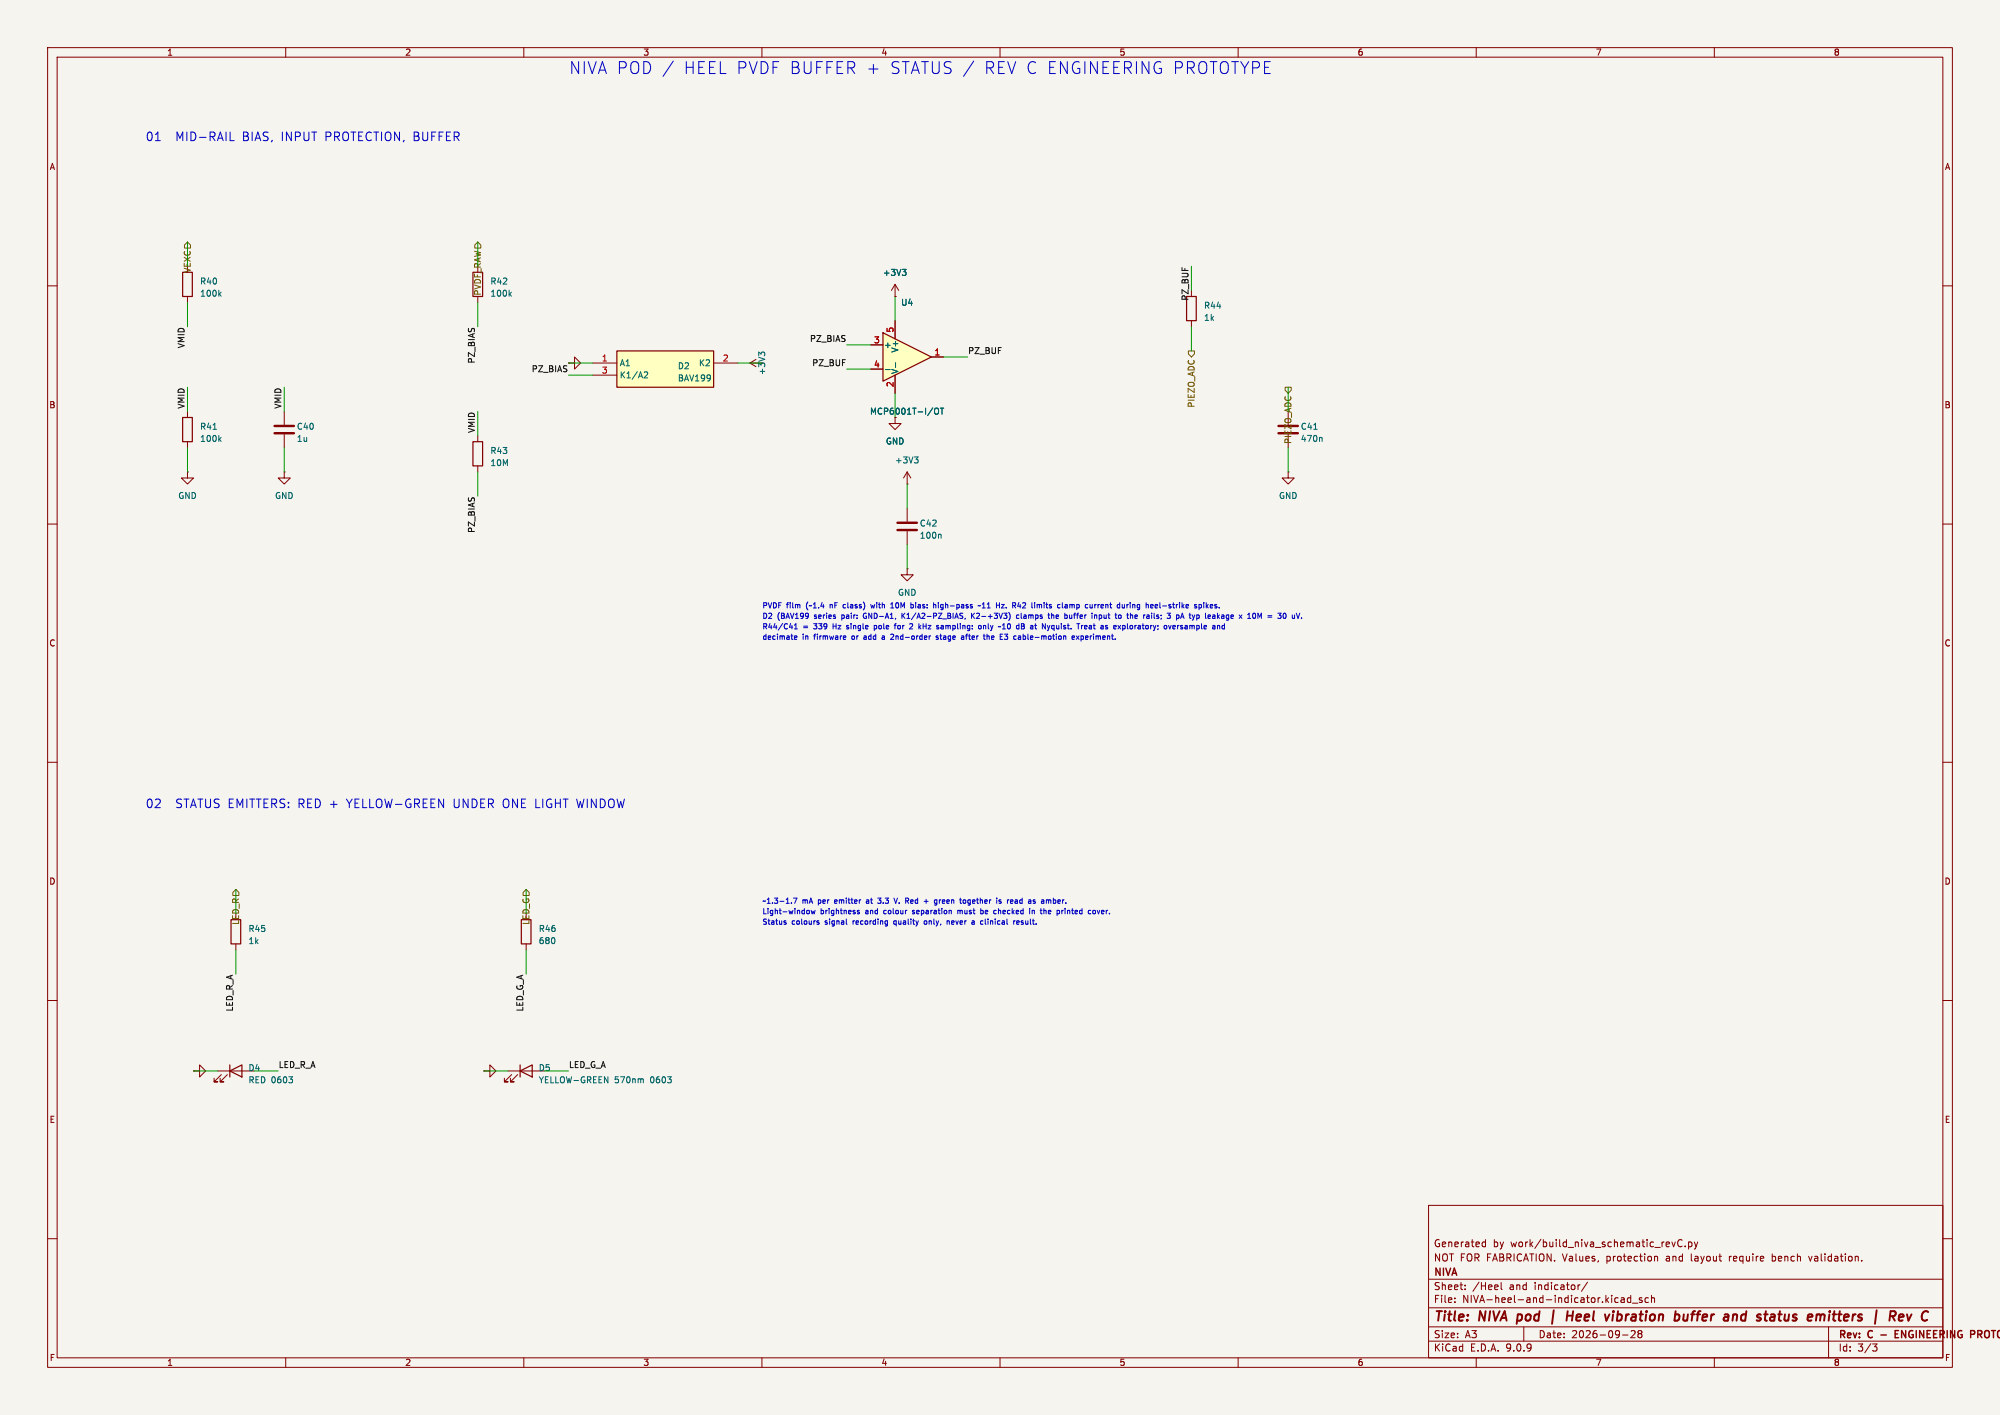
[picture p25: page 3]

NIVA POD / HEEL PVDF BUFFER + STATUS / REV C ENGINEERING PROTOTYPE

Id: 3/3 Title: NIVA pod | Heel vibration buffer and status emitters | Rev C

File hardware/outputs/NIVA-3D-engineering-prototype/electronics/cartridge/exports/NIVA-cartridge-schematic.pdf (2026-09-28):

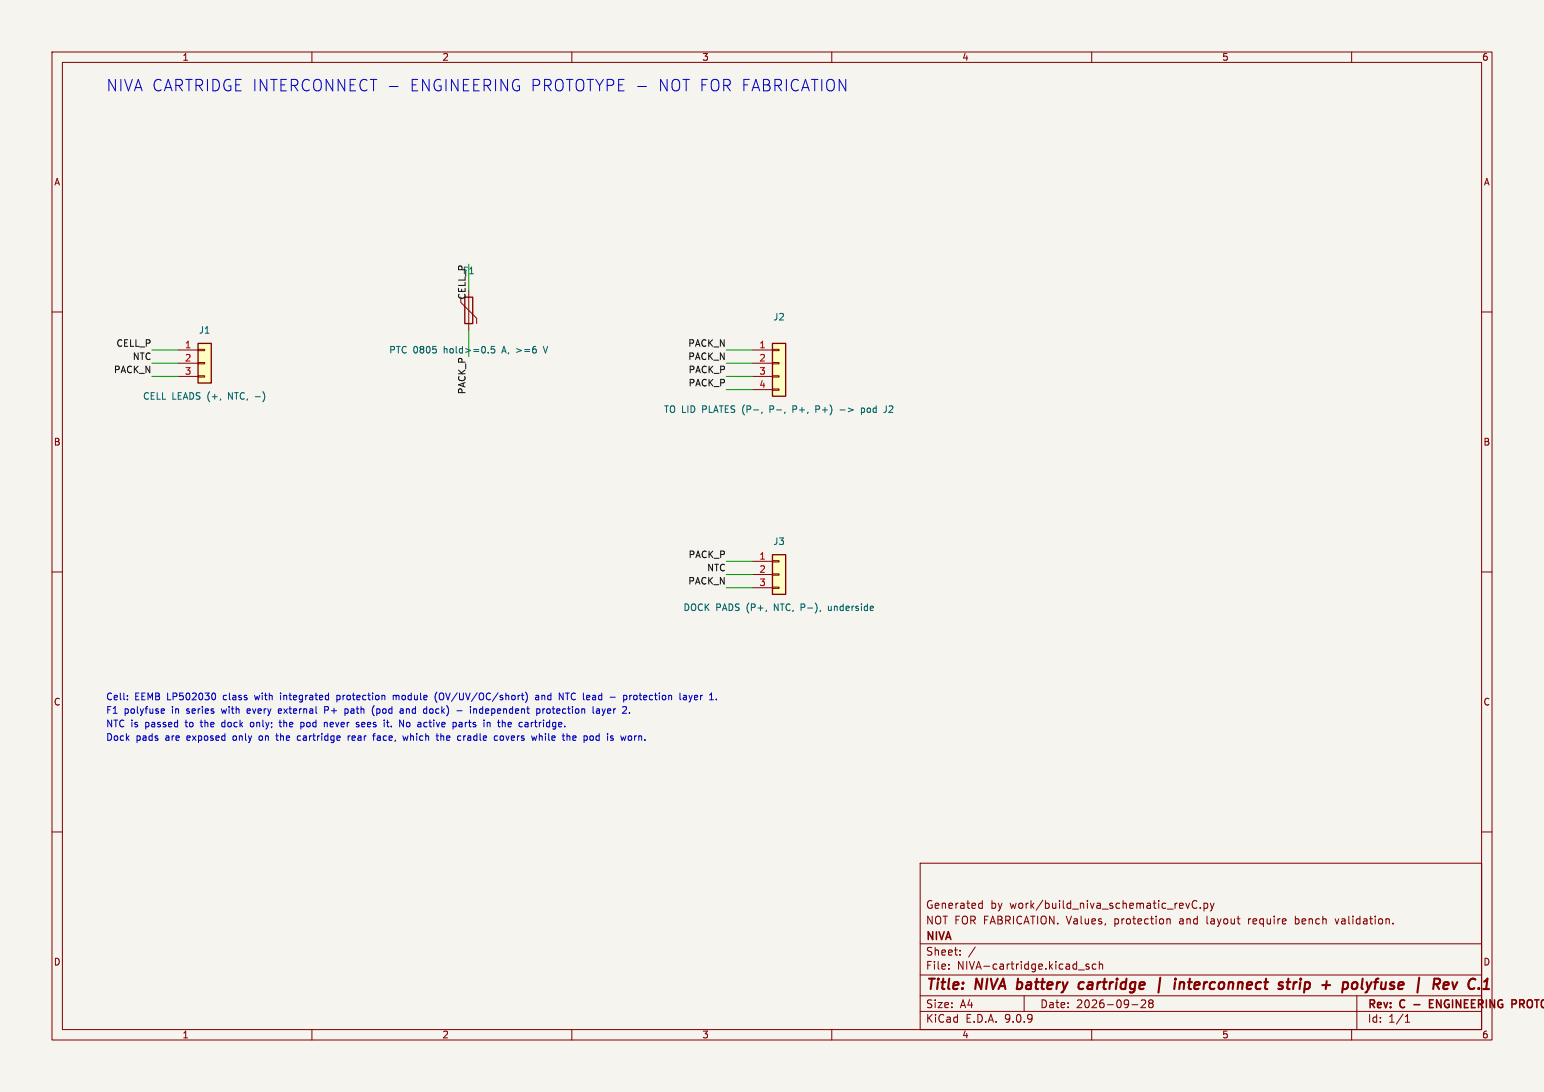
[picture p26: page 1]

File: NIVA-cartridge.kicad_sch Sheet: / NIVA

Id: 1/1 Title: NIVA battery cartridge | interconnect strip + polyfuse | Rev C.1

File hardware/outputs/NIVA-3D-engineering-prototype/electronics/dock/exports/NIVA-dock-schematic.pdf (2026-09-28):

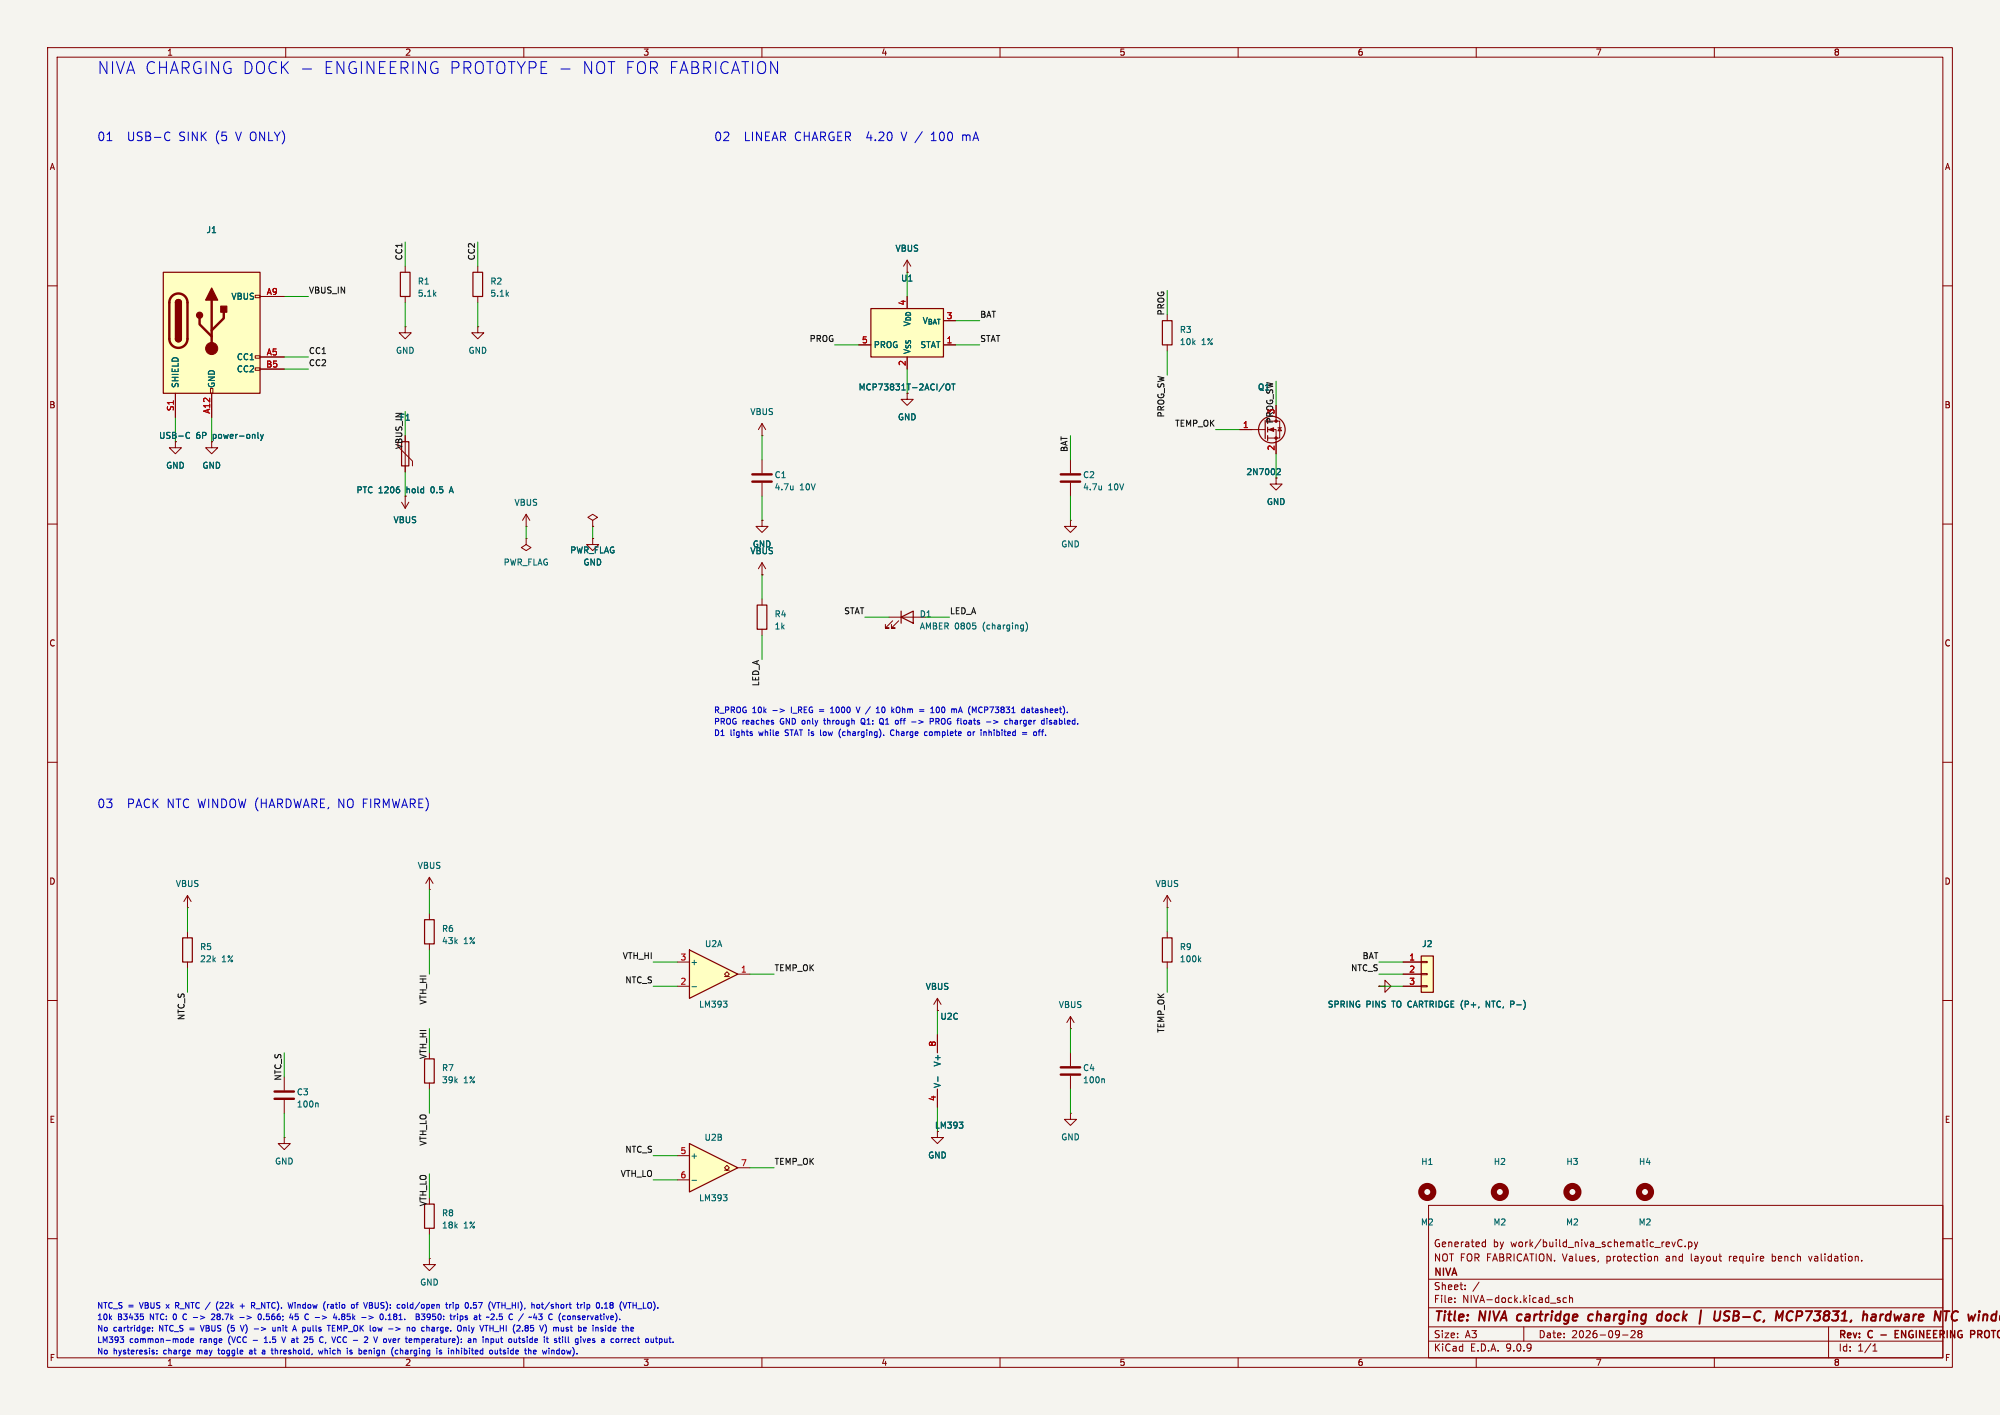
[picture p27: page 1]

NIVA CHARGING DOCK - ENGINEERING PROTOTYPE - NOT FOR FABRICATION

J2 SPRING PINS TO CARTRIDGE (P+, NTC, P-) GND

J2 SPRING PINS TO CARTRIDGE (P+, NTC, P-) 1

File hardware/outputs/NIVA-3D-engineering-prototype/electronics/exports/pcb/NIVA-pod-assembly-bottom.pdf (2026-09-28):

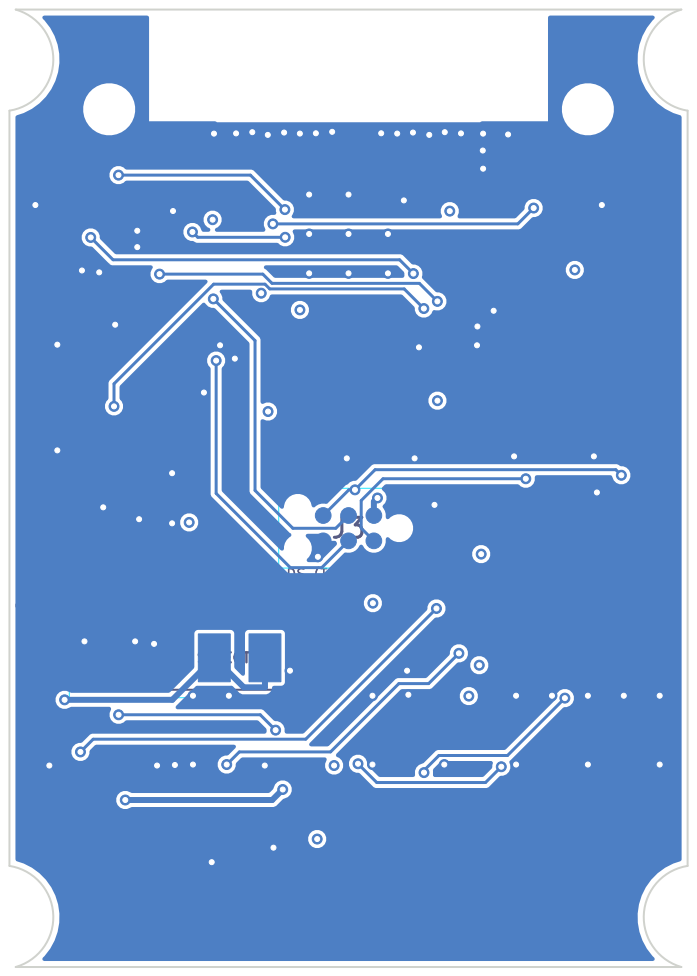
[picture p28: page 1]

Id: 1/1 Title: File: NIVA-pod.kicad_pcb Sheet:

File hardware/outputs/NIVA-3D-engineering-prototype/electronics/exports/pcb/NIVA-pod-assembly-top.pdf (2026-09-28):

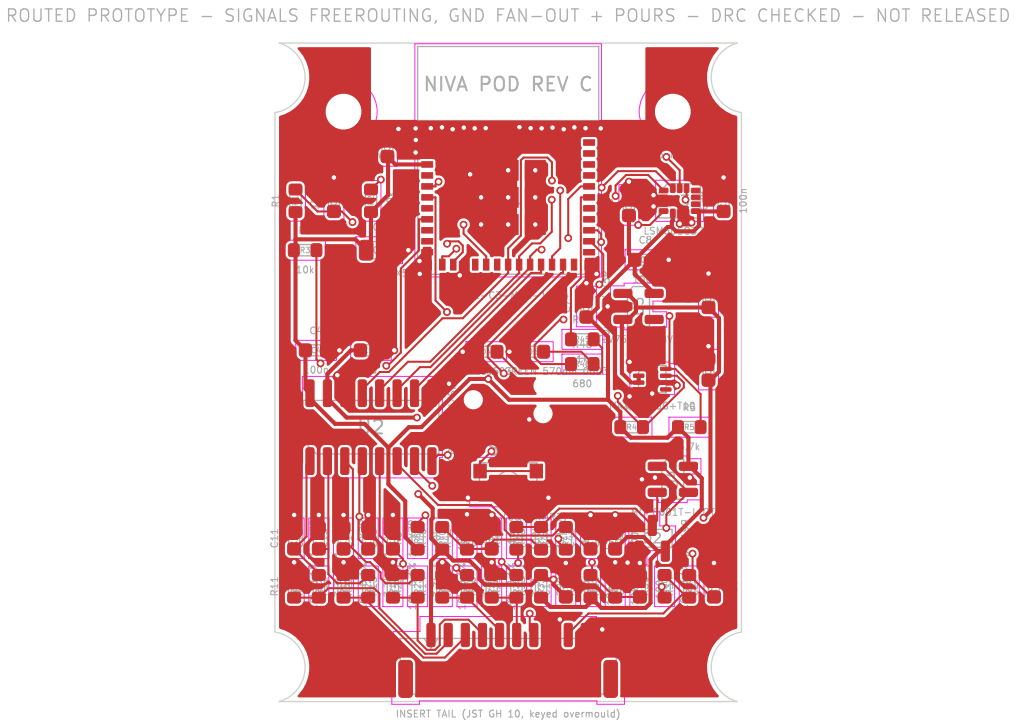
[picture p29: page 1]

ROUTED PROTOTYPE - SIGNALS FREEROUTING, GND FAN-OUT + POURS - DRC CHECKED - NOT RELEASED NIVA POD REV C

INSERT TAIL (JST GH 10, keyed overmould) J1 MCP3208-CI/SL U2

Id: 1/1 Title: File: NIVA-pod.kicad_pcb Sheet:

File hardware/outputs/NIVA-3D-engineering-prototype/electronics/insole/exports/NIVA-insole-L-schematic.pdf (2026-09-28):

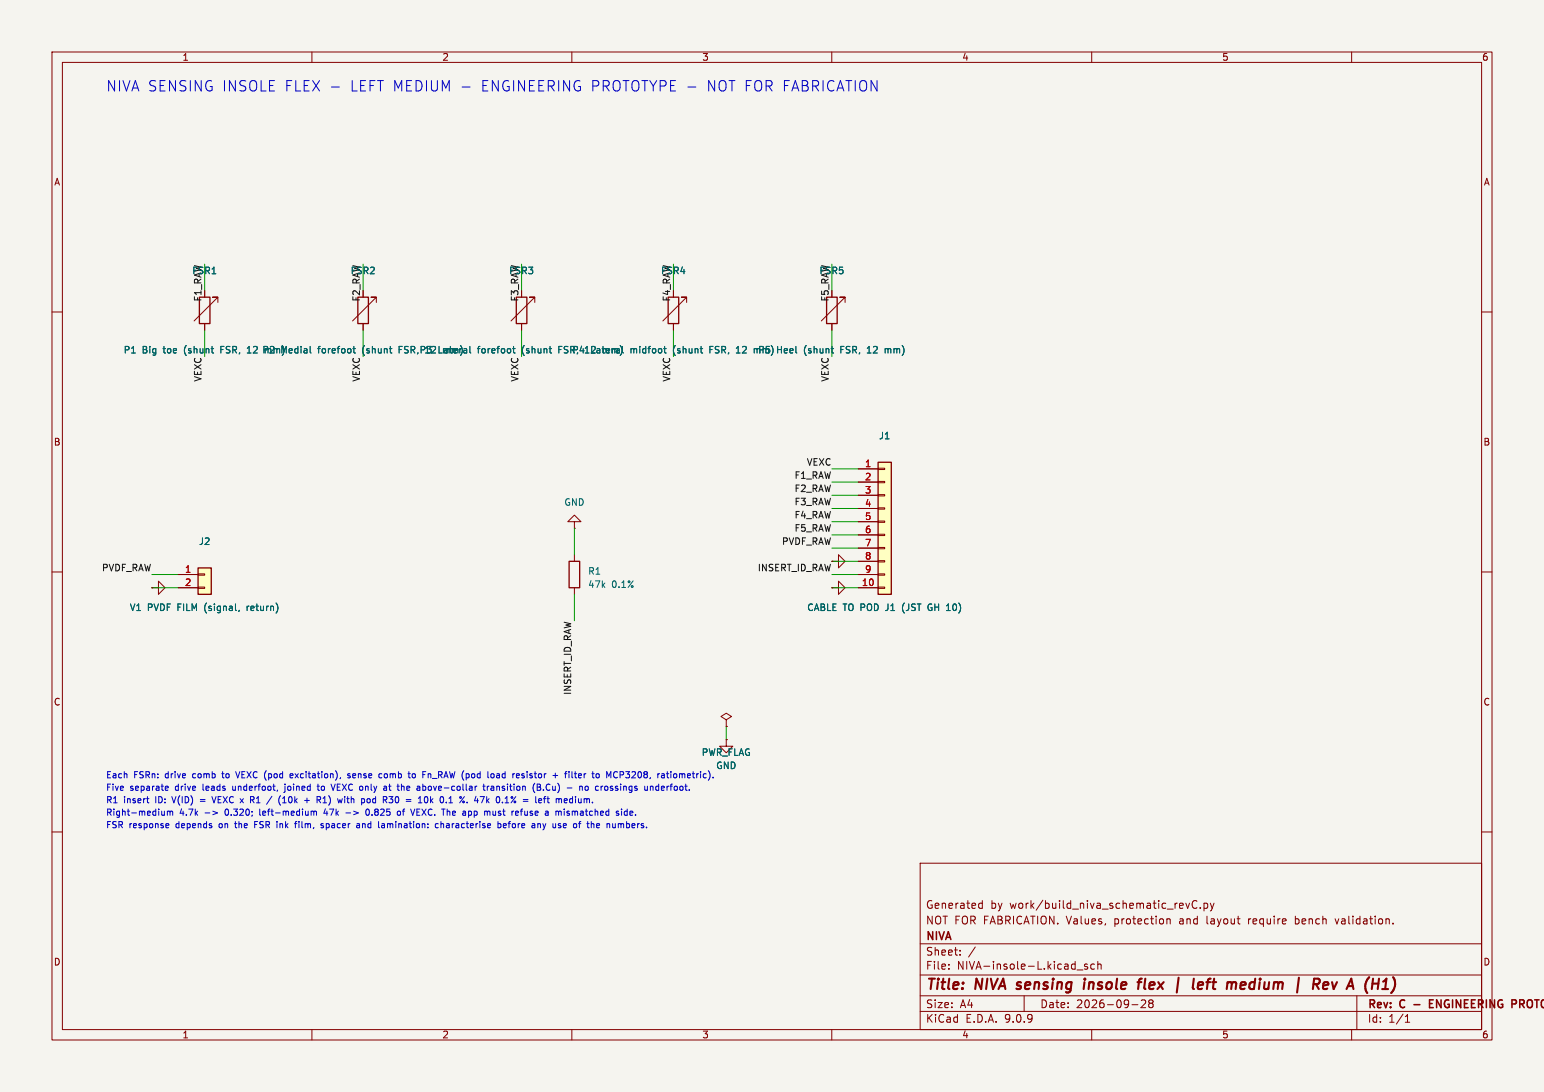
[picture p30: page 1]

J1 CABLE TO POD J1 (JST GH 10) GND

Id: 1/1 Title: NIVA sensing insole flex | left medium | Rev A (H1) File: NIVA-insole-L.kicad_sch Sheet: / NIVA

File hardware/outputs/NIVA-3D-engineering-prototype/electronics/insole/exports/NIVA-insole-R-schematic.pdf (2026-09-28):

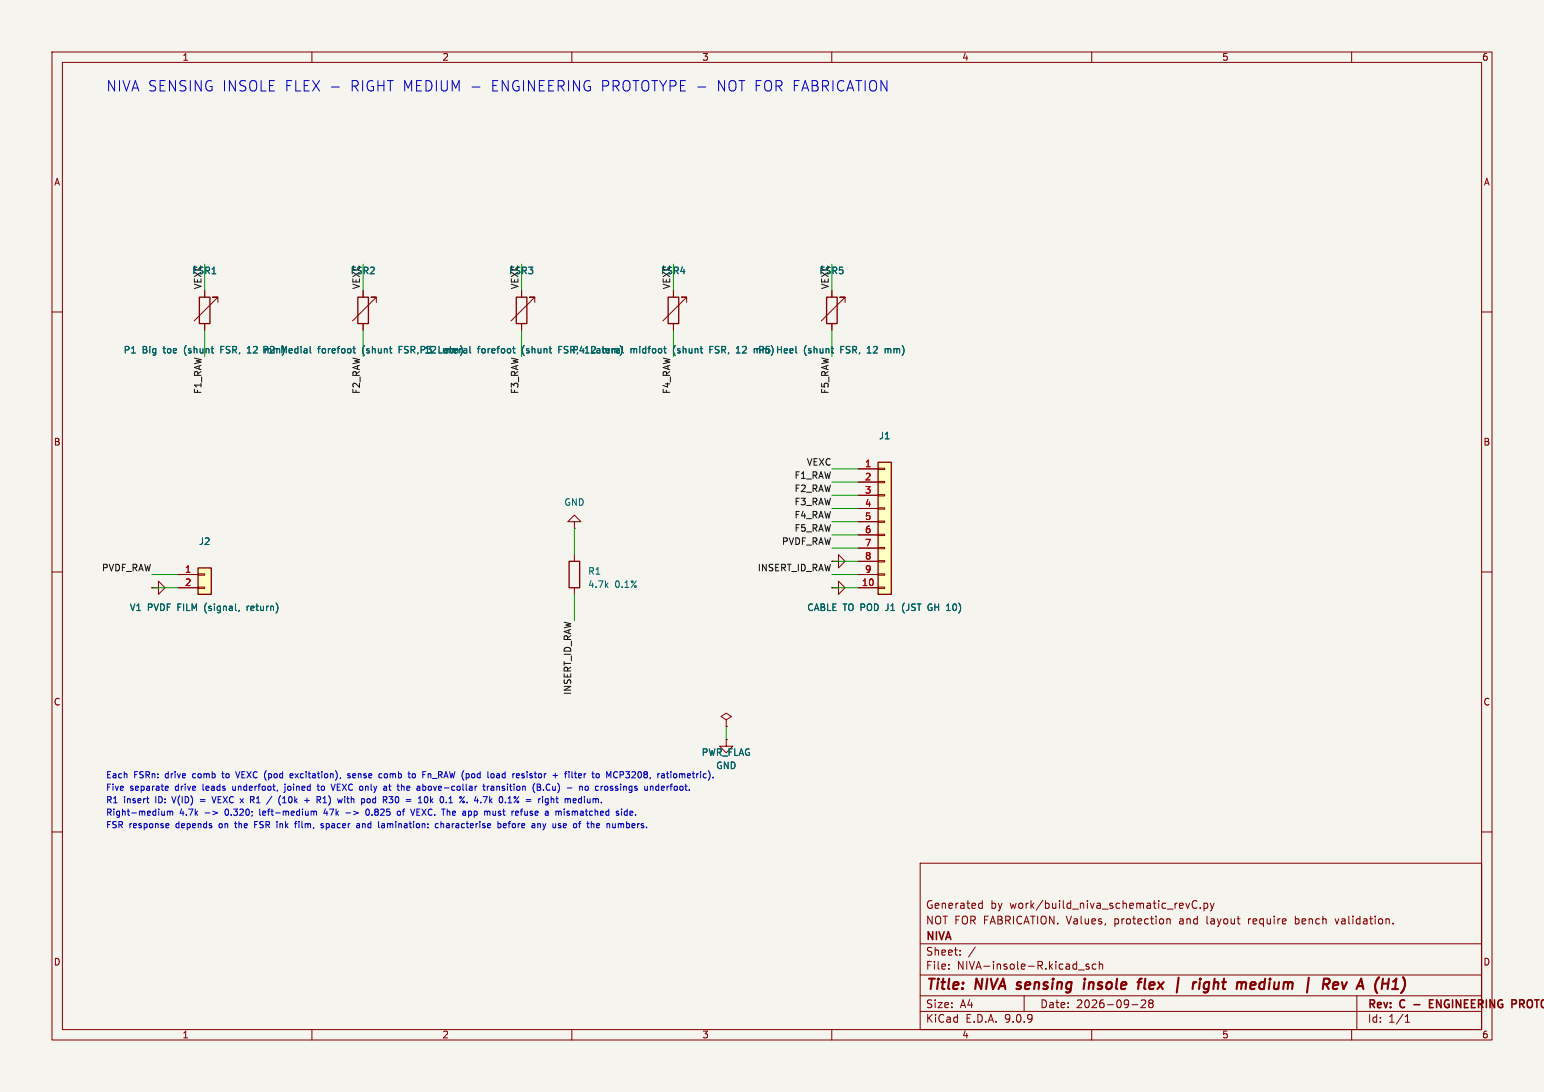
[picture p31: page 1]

NIVA SENSING INSOLE FLEX - RIGHT MEDIUM - ENGINEERING PROTOTYPE - NOT FOR FABRICATION

J1 CABLE TO POD J1 (JST GH 10) F1_RAW

Id: 1/1 Title: NIVA sensing insole flex | right medium | Rev A (H1) File: NIVA-insole-R.kicad_sch Sheet: / NIVA

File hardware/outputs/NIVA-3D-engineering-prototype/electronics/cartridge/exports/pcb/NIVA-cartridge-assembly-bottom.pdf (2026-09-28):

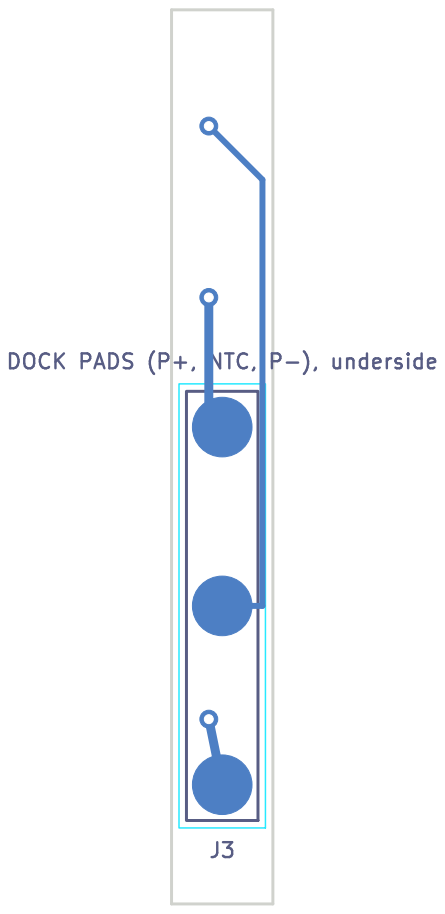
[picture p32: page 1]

Id: 1/1 Title: File: NIVA-cartridge.kicad_pcb Sheet:

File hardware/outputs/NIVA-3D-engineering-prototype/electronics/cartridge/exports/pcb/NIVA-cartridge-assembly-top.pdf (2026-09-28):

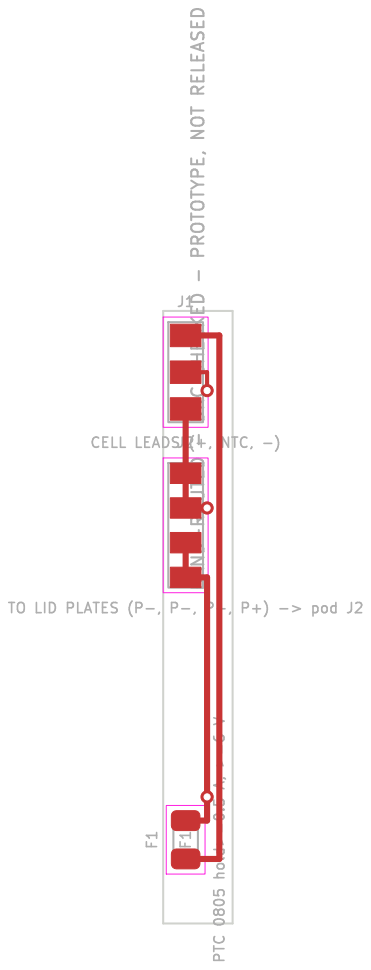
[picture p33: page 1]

Id: 1/1 Title: File: NIVA-cartridge.kicad_pcb Sheet: HAND-ROUTED - DRC CHECKED - PROTOTYPE, NOT RELEASED

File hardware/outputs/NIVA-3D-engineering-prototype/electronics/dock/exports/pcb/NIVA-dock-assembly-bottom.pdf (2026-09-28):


Id: 1/1 Title: File: NIVA-dock.kicad_pcb Sheet:

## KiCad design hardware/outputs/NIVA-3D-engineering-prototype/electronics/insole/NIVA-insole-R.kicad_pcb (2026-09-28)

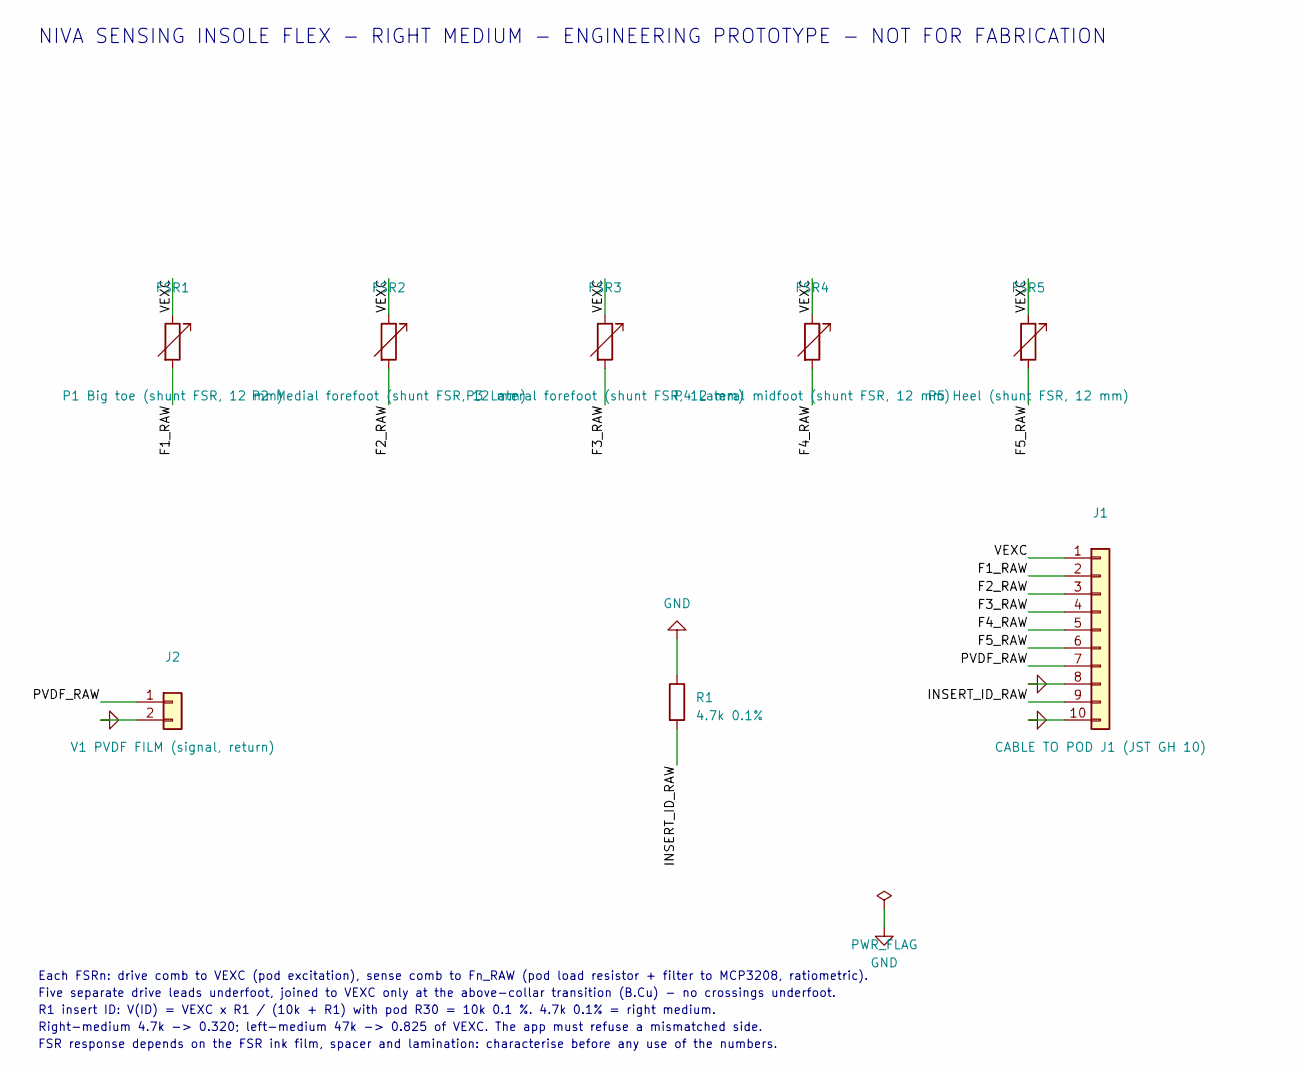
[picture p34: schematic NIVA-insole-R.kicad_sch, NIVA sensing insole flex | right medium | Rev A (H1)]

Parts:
FSR1: P1 Big toe (shunt FSR, 12 mm); FSR_Interdigitated_D12mm
FSR2: P2 Medial forefoot (shunt FSR, 12 mm); FSR_Interdigitated_D12mm
FSR3: P3 Lateral forefoot (shunt FSR, 12 mm); FSR_Interdigitated_D12mm
FSR4: P4 Lateral midfoot (shunt FSR, 12 mm); FSR_Interdigitated_D12mm
FSR5: P5 Heel (shunt FSR, 12 mm); FSR_Interdigitated_D12mm
J1: CABLE TO POD J1 (JST GH 10); WirePads_1x10_P2.0mm_LaneOrder
J2: V1 PVDF FILM (signal, return); PVDF_BondPads_2x6x2mm
R1: 4.7k 0.1%; R_0603_1608Metric; MPN 0603 thin film 4.7k 0.1% (right medium 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

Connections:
/F1_RAW: FSR1.2, J1.2
/F2_RAW: FSR2.2, J1.3
/F3_RAW: FSR3.2, J1.4
/F4_RAW: FSR4.2, J1.5
/F5_RAW: FSR5.2, J1.6
/INSERT_ID_RAW: J1.9, R1.2
/PVDF_RAW: J1.7, J2.1
/VEXC: FSR1.1, FSR2.1, FSR3.1, FSR4.1, FSR5.1, J1.1
GND: J1.8, J1.10, J2.2, R1.1

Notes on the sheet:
NIVA SENSING INSOLE FLEX - RIGHT MEDIUM - ENGINEERING PROTOTYPE - NOT FOR FABRICATION
Each FSRn: drive comb to VEXC (pod excitation), sense comb to Fn_RAW (pod load resistor + filter to MCP3208, ratiometric).
Five separate drive leads underfoot, joined to VEXC only at the above-collar transition (B.Cu) - no crossings underfoot.
R1 insert ID: V(ID) = VEXC x R1 / (10k + R1) with pod R30 = 10k 0.1 %. 4.7k 0.1% = right medium.
Right-medium 4.7k -> 0.320; left-medium 47k -> 0.825 of VEXC. The app must refuse a mismatched side.
FSR response depends on the FSR ink film, spacer and lamination: characterise before any use of the numbers.

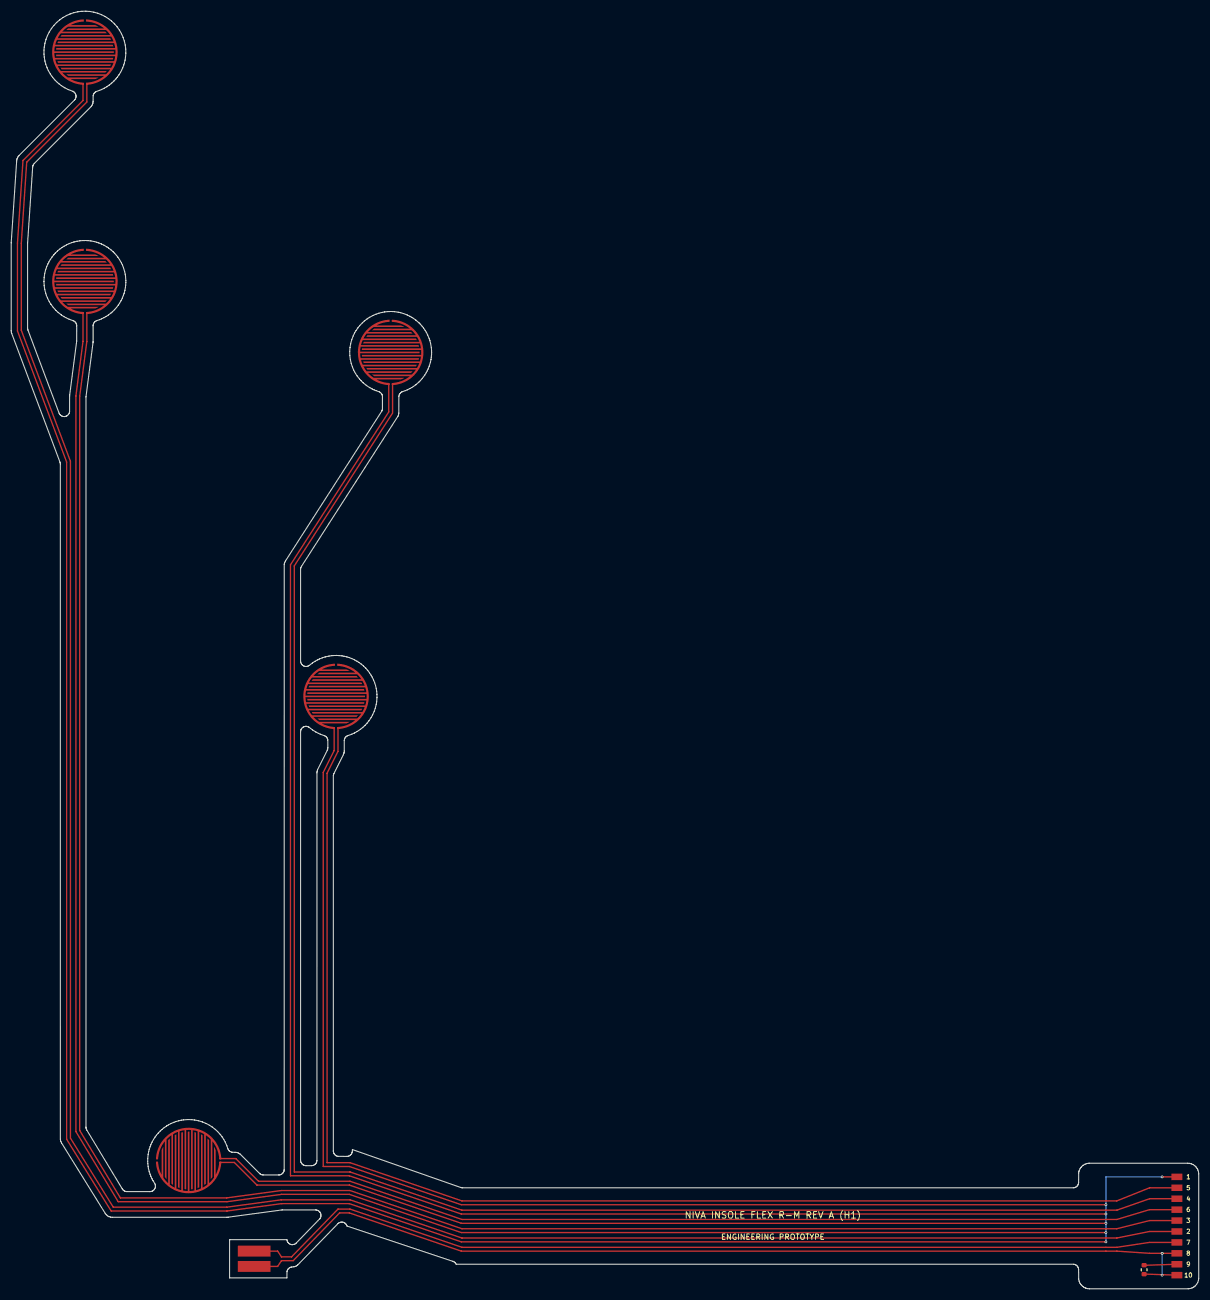
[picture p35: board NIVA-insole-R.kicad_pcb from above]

Board: 2 copper layers, 217.5 x 234.0 mm, 8 parts (0 on the bottom side), 9 nets.

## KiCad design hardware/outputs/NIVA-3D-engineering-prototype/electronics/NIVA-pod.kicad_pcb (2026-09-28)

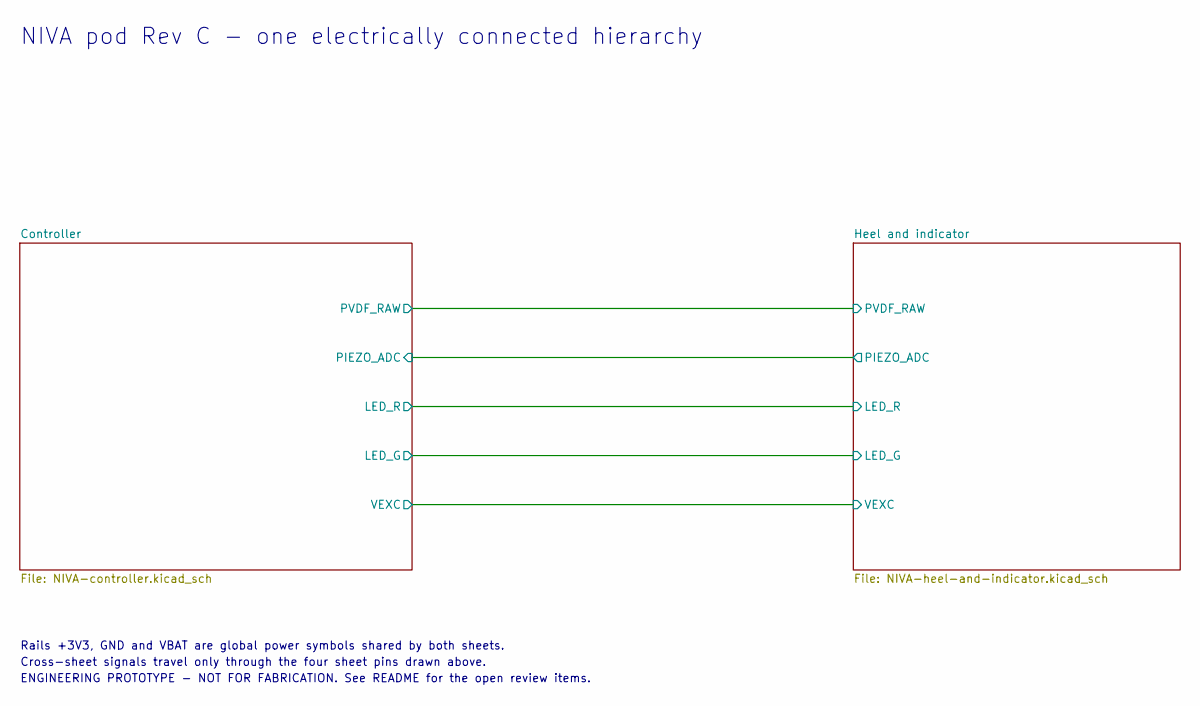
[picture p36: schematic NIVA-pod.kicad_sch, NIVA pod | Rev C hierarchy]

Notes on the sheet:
NIVA pod Rev C - one electrically connected hierarchy
Rails +3V3, GND and VBAT are global power symbols shared by both sheets.
Cross-sheet signals travel only through the four sheet pins drawn above.
ENGINEERING PROTOTYPE - NOT FOR FABRICATION. See README for the open review items.

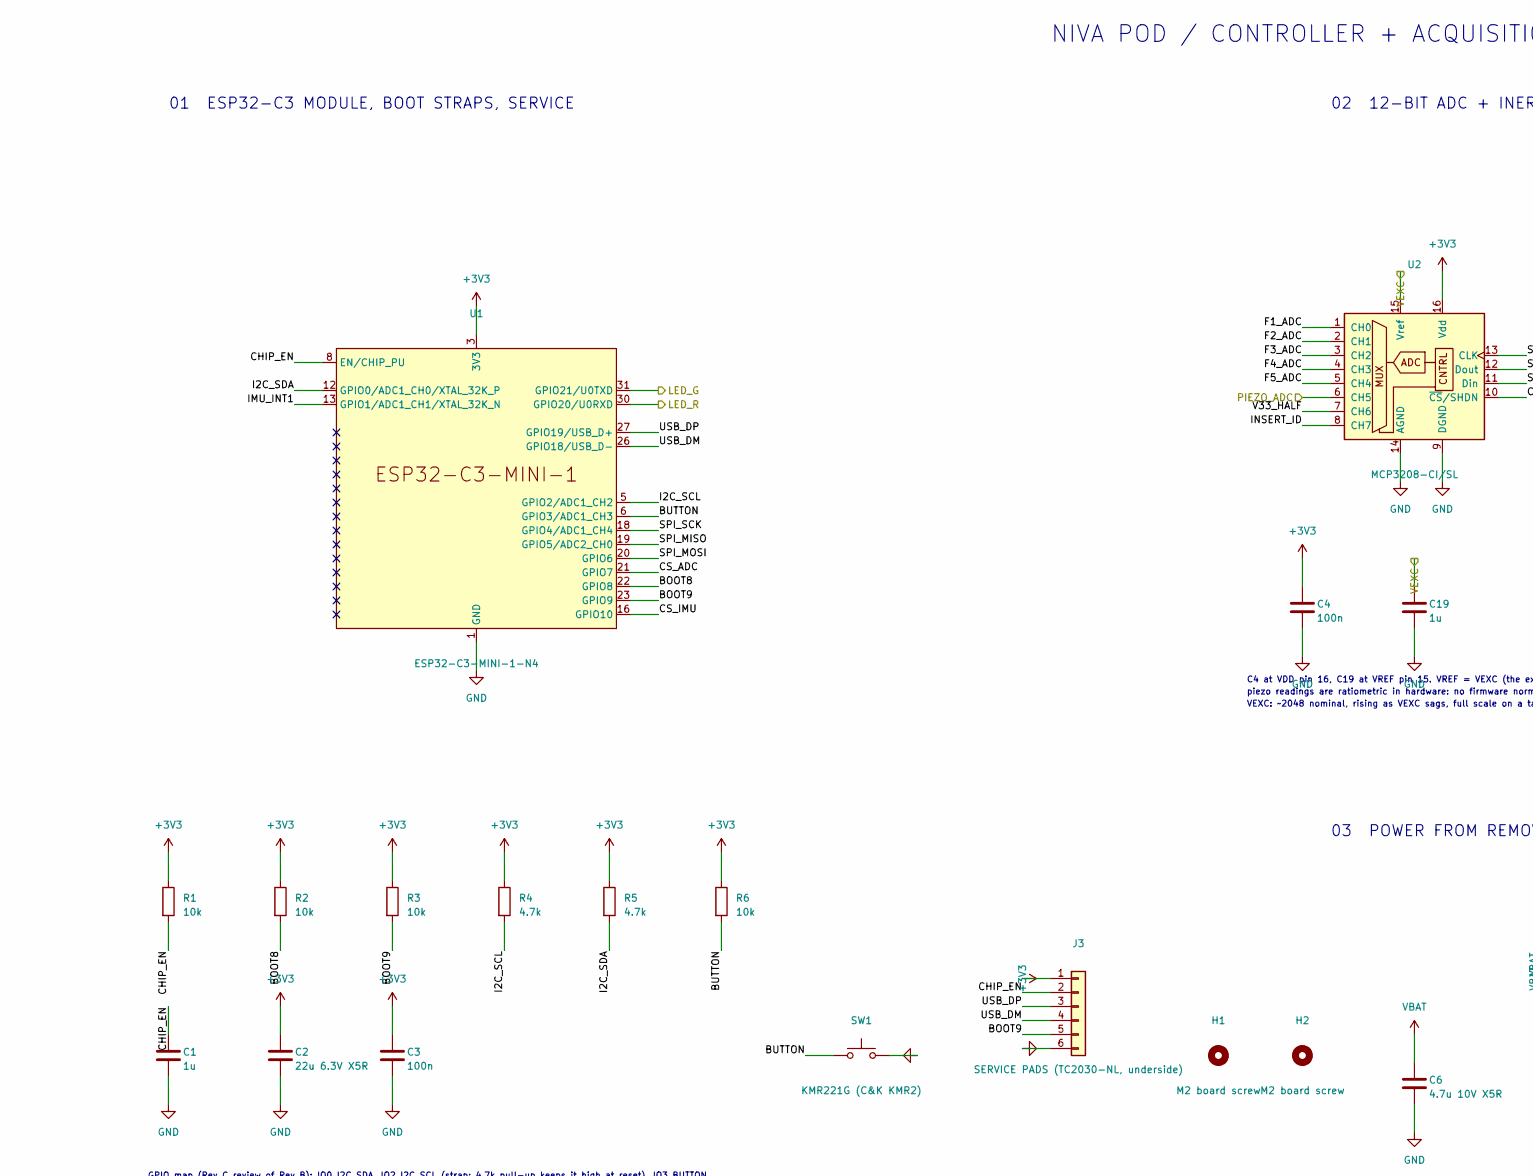
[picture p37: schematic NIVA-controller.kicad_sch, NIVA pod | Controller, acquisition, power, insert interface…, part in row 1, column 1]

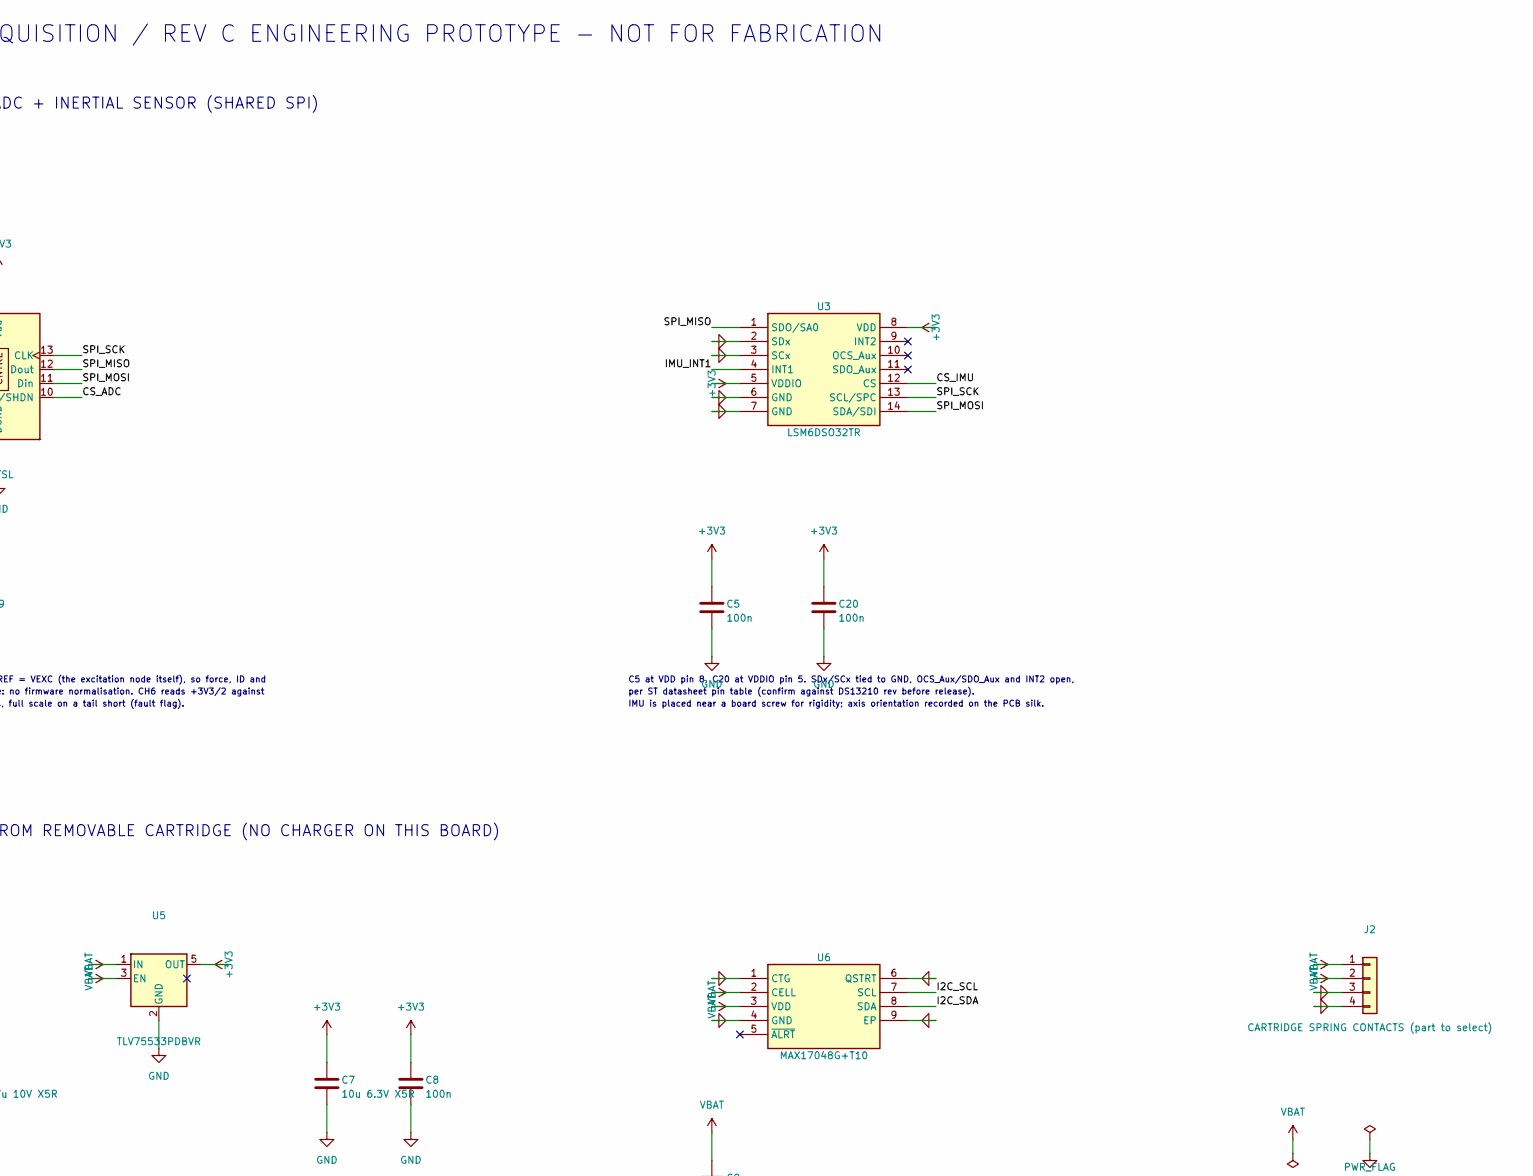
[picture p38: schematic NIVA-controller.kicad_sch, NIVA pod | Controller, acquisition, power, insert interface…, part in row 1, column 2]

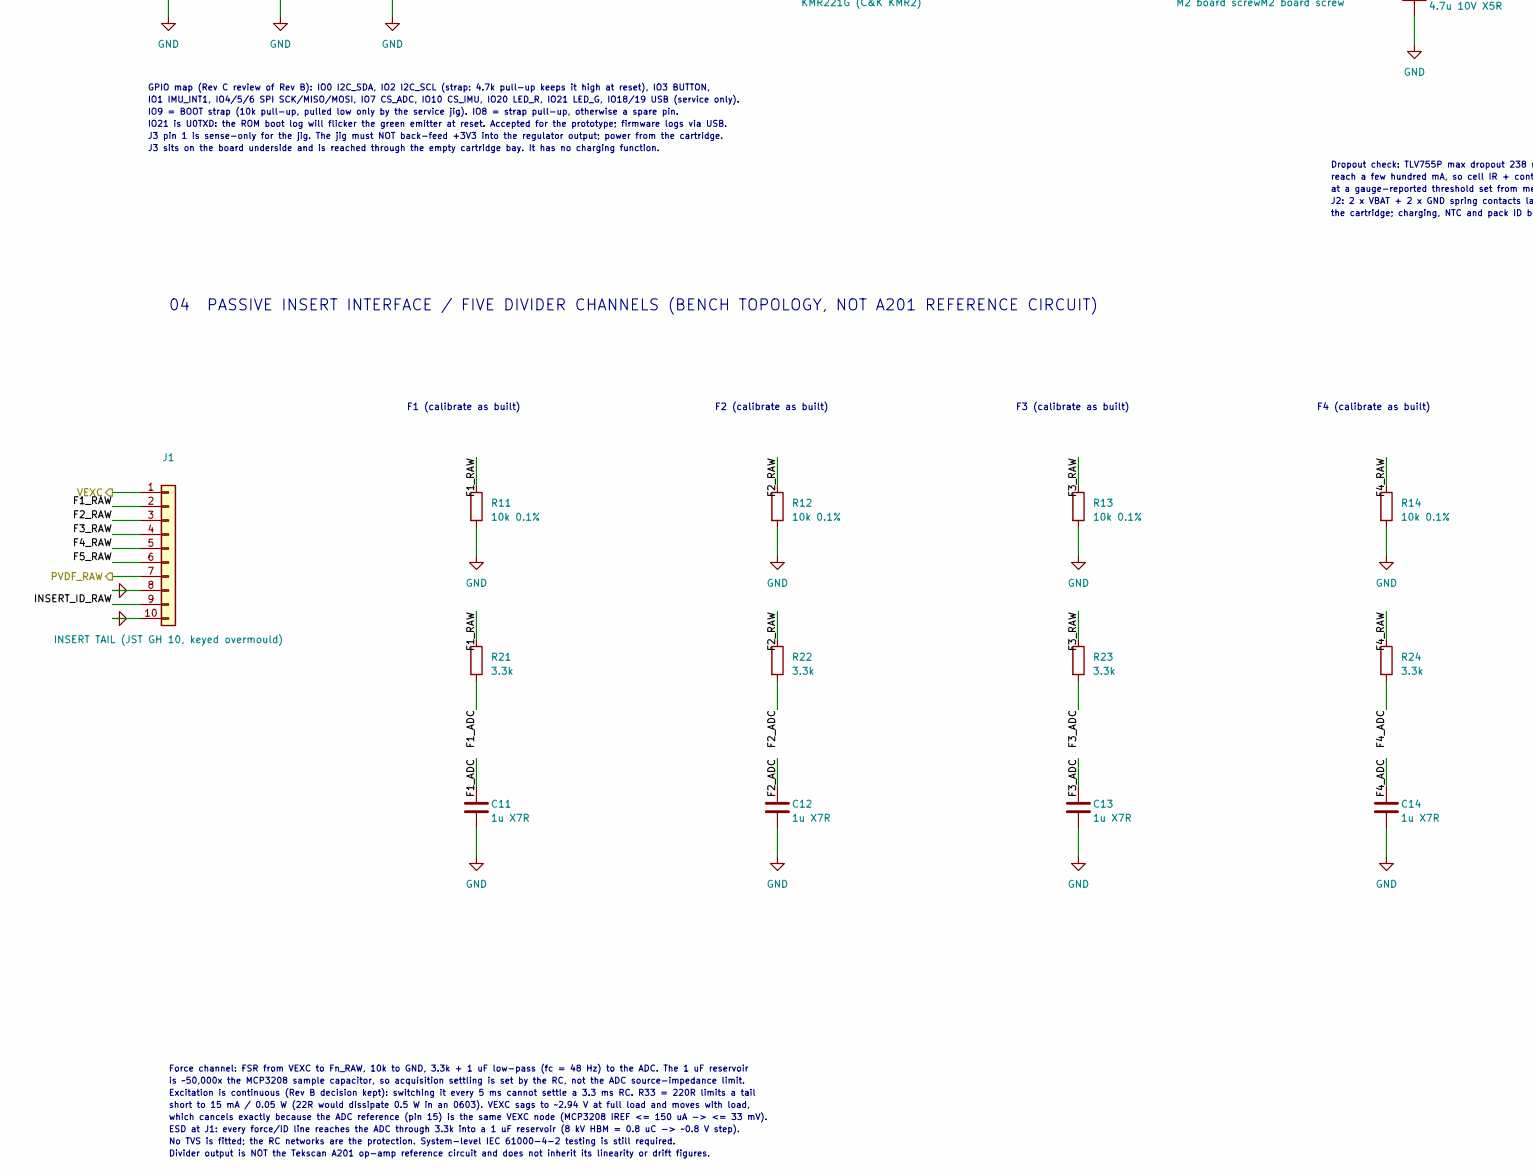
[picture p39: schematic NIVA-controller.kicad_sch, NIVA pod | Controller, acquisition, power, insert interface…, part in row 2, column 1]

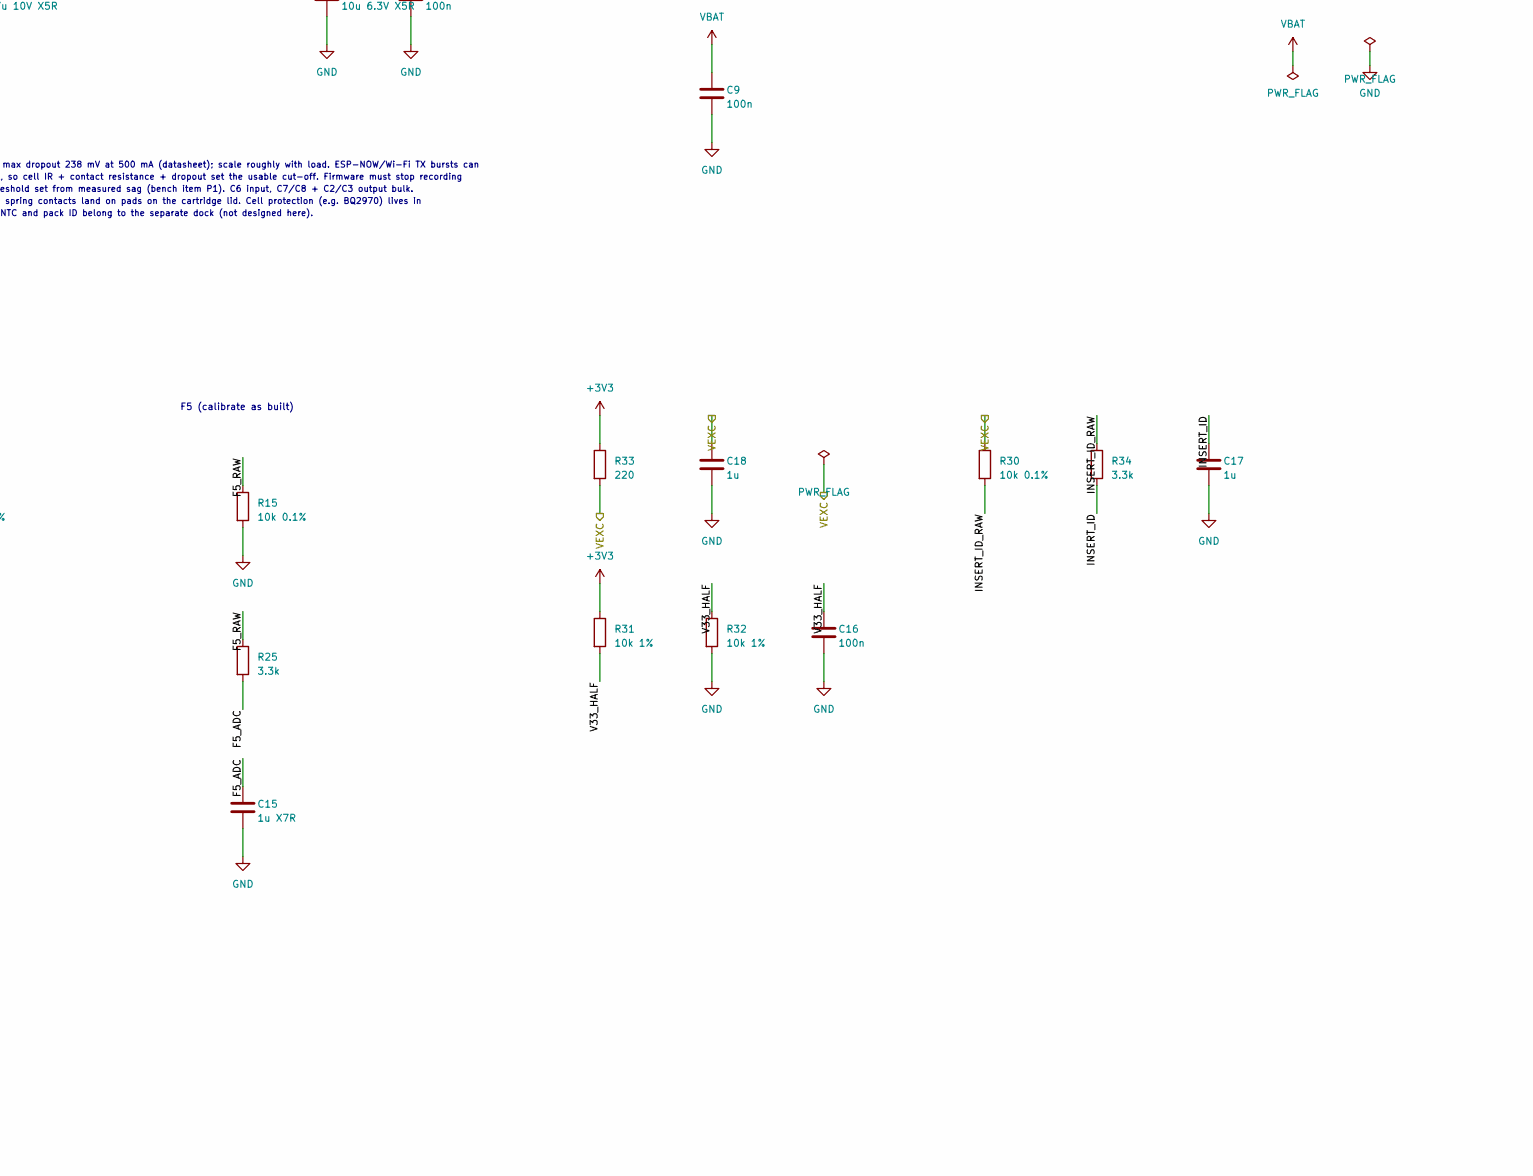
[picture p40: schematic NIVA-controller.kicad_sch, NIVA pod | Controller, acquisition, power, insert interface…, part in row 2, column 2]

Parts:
C1, C17, C18, C19: 1u; C_0603_1608Metric
C2: 22u 6.3V X5R; C_0805_2012Metric
C3, C4, C5, C8, C9, C16, C20: 100n; C_0603_1608Metric
C6: 4.7u 10V X5R; C_0603_1608Metric
C7: 10u 6.3V X5R; C_0603_1608Metric
C11, C12, C13, C14, C15: 1u X7R; C_0603_1608Metric
H1, H2: M2 board screw; MountingHole_2.2mm_M2
J1: INSERT TAIL (JST GH 10, keyed overmould); JST_GH_SM10B-GHS-TB_1x10-1MP_P1.25mm_Horizontal; MPN SM10B-GHS-TB
J2: CARTRIDGE SPRING CONTACTS (part to select); SpringContact_1x04_P2.54mm_Vertical_SMD
J3: SERVICE PADS (TC2030-NL, underside); Tag-Connect_TC2030-IDC-NL_2x03_P1.27mm_Vertical
R1, R2, R3, R6: 10k; R_0603_1608Metric
R4, R5: 4.7k; R_0603_1608Metric
R11, R12, R13, R14, R15, R30: 10k 0.1%; R_0603_1608Metric
R21, R22, R23, R24, R25, R34: 3.3k; R_0603_1608Metric
R31, R32: 10k 1%; R_0603_1608Metric
R33: 220; R_0603_1608Metric
SW1: KMR221G (C&K KMR2); SW_Push_1P1T_NO_CK_KMR2
U1: ESP32-C3-MINI-1-N4; ESP32-C3-MINI-1; MPN ESP32-C3-MINI-1-N4
U2: MCP3208-CI/SL; SOIC-16_3.9x9.9mm_P1.27mm; MPN MCP3208-CI/SL
U3: LSM6DSO32TR; LGA-14_3x2.5mm_P0.5mm_LayoutBorder3x4y; MPN LSM6DSO32TR
U5: TLV75533PDBVR; SOT-23-5; MPN TLV75533PDBVR
U6: MAX17048G+T10; TDFN-8-1EP_2x2mm_P0.5mm_EP0.8x1.2mm; MPN MAX17048G+T10

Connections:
+3V3: C2.1, C3.1, C4.1, C5.1, C7.1, C8.1, C20.1, J3.1, R1.1, R2.1, R3.1, R4.1, R5.1, R6.1, R31.1, R33.1, U1.3 (3V3), U2.16 (Vdd), U3.5 (VDDIO), U3.8 (VDD), U5.5 (OUT); also elsewhere on the board
/Controller/BOOT8: R2.2, U1.22 (GPIO8)
/Controller/BOOT9: J3.5, R3.2, U1.23 (GPIO9)
/Controller/BUTTON: R6.2, SW1.1, U1.6 (GPIO3/ADC1_CH3)
/Controller/CHIP_EN: C1.1, J3.2, R1.2, U1.8 (EN/CHIP_PU)
/Controller/CS_ADC: U1.21 (GPIO7), U2.10 (~CS/SHDN)
/Controller/CS_IMU: U1.16 (GPIO10), U3.12 (CS)
/Controller/F1_ADC: C11.1, R21.2, U2.1 (CH0)
/Controller/F1_RAW: J1.2, R11.1, R21.1
/Controller/F2_ADC: C12.1, R22.2, U2.2 (CH1)
/Controller/F2_RAW: J1.3, R12.1, R22.1
/Controller/F3_ADC: C13.1, R23.2, U2.3 (CH2)
/Controller/F3_RAW: J1.4, R13.1, R23.1
/Controller/F4_ADC: C14.1, R24.2, U2.4 (CH3)
/Controller/F4_RAW: J1.5, R14.1, R24.1
/Controller/F5_ADC: C15.1, R25.2, U2.5 (CH4)
/Controller/F5_RAW: J1.6, R15.1, R25.1
/Controller/I2C_SCL: R4.2, U1.5 (GPIO2/ADC1_CH2), U6.7 (SCL)
/Controller/I2C_SDA: R5.2, U1.12 (GPIO0/ADC1_CH0/XTAL_32K_P), U6.8 (SDA)
/Controller/IMU_INT1: U1.13 (GPIO1/ADC1_CH1/XTAL_32K_N), U3.4 (INT1)
/Controller/INSERT_ID: C17.1, R34.2, U2.8 (CH7)
/Controller/INSERT_ID_RAW: J1.9, R30.2, R34.1
/Controller/LED_G: U1.31 (GPIO21/U0TXD); also elsewhere on the board
/Controller/LED_R: U1.30 (GPIO20/U0RXD); also elsewhere on the board
/Controller/PIEZO_ADC: U2.6 (CH5); also elsewhere on the board
/Controller/PVDF_RAW: J1.7; also elsewhere on the board
/Controller/SPI_MISO: U1.19 (GPIO5/ADC2_CH0), U2.12 (Dout), U3.1 (SDO/SA0)
/Controller/SPI_MOSI: U1.20 (GPIO6), U2.11 (Din), U3.14 (SDA/SDI)
/Controller/SPI_SCK: U1.18 (GPIO4/ADC1_CH4), U2.13 (CLK), U3.13 (SCL/SPC)
/Controller/USB_DM: J3.4, U1.26 (GPIO18/USB_D-)
/Controller/USB_DP: J3.3, U1.27 (GPIO19/USB_D+)
/Controller/V33_HALF: C16.1, R31.2, R32.1, U2.7 (CH6)
/Controller/VEXC: C18.1, C19.1, J1.1, R30.1, R33.2, U2.15 (Vref); also elsewhere on the board
GND: C1.2, C2.2, C3.2, C4.2, C5.2, C6.2, C7.2, C8.2, C9.2, C11.2, C12.2, C13.2, C14.2, C15.2, C16.2, C17.2, C18.2, C19.2, C20.2, J1.8, J1.10, J2.3, J2.4, J3.6, R11.2, R12.2, R13.2, R14.2, R15.2, R32.2, SW1.2, U1.1 (GND), U1.2 (GND), U1.11 (GND), U1.14 (GND), U1.36 (GND), U1.37 (GND), U1.38 (GND), U1.39 (GND), U1.40 (GND), U1.41 (GND), U1.42 (GND), U1.43 (GND), U1.44 (GND), U1.45 (GND), U1.46 (GND), U1.47 (GND), U1.48 (GND), U1.49 (GND), U1.50 (GND), U1.51 (GND), U1.52 (GND), U1.53 (GND), U2.9 (DGND), U2.14 (AGND), U3.2 (SDx), U3.3 (SCx), U3.6 (GND), U3.7 (GND), U5.2 (GND), U6.1 (CTG), U6.4 (GND), U6.6 (QSTRT), U6.9 (EP); also elsewhere on the board
VBAT: C6.1, C9.1, J2.1, J2.2, U5.1 (IN), U5.3 (EN), U6.2 (CELL), U6.3 (VDD)

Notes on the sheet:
NIVA POD / CONTROLLER + ACQUISITION / REV C ENGINEERING PROTOTYPE - NOT FOR FABRICATION
01 ESP32-C3 MODULE, BOOT STRAPS, SERVICE
GPIO map (Rev C review of Rev B): IO0 I2C_SDA, IO2 I2C_SCL (strap: 4.7k pull-up keeps it high at reset), IO3 BUTTON,
IO1 IMU_INT1, IO4/5/6 SPI SCK/MISO/MOSI, IO7 CS_ADC, IO10 CS_IMU, IO20 LED_R, IO21 LED_G, IO18/19 USB (service only).
IO9 = BOOT strap (10k pull-up, pulled low only by the service jig). IO8 = strap pull-up, otherwise a spare pin.
IO21 is U0TXD: the ROM boot log will flicker the green emitter at reset. Accepted for the prototype; firmware logs via USB.
J3 pin 1 is sense-only for the jig. The jig must NOT back-feed +3V3 into the regulator output; power from the cartridge.
J3 sits on the board underside and is reached through the empty cartridge bay. It has no charging function.
02 12-BIT ADC + INERTIAL SENSOR (SHARED SPI)
C4 at VDD pin 16, C19 at VREF pin 15. VREF = VEXC (the excitation node itself), so force, ID and
piezo readings are ratiometric in hardware: no firmware normalisation. CH6 reads +3V3/2 against
VEXC: ~2048 nominal, rising as VEXC sags, full scale on a tail short (fault flag).
C5 at VDD pin 8, C20 at VDDIO pin 5. SDx/SCx tied to GND, OCS_Aux/SDO_Aux and INT2 open,
per ST datasheet pin table (confirm against DS13210 rev before release).
IMU is placed near a board screw for rigidity; axis orientation recorded on the PCB silk.
03 POWER FROM REMOVABLE CARTRIDGE (NO CHARGER ON THIS BOARD)
Dropout check: TLV755P max dropout 238 mV at 500 mA (datasheet); scale roughly with load. ESP-NOW/Wi-Fi TX bursts can
reach a few hundred mA, so cell IR + contact resistance + dropout set the usable cut-off. Firmware must stop recording
at a gauge-reported threshold set from measured sag (bench item P1). C6 input, C7/C8 + C2/C3 output bulk.
J2: 2 x VBAT + 2 x GND spring contacts land on pads on the cartridge lid. Cell protection (e.g. BQ2970) lives in
the cartridge; charging, NTC and pack ID belong to the separate dock (not designed here).
04 PASSIVE INSERT INTERFACE / FIVE DIVIDER CHANNELS (BENCH TOPOLOGY, NOT A201 REFERENCE CIRCUIT)
F1 (calibrate as built)
F2 (calibrate as built)
F3 (calibrate as built)
F4 (calibrate as built)
F5 (calibrate as built)
Force channel: FSR from VEXC to Fn_RAW, 10k to GND, 3.3k + 1 uF low-pass (fc = 48 Hz) to the ADC. The 1 uF reservoir
is ~50,000x the MCP3208 sample capacitor, so acquisition settling is set by the RC, not the ADC source-impedance limit.
Excitation is continuous (Rev B decision kept): switching it every 5 ms cannot settle a 3.3 ms RC. R33 = 220R limits a tail
short to 15 mA / 0.05 W (22R would dissipate 0.5 W in an 0603). VEXC sags to ~2.94 V at full load and moves with load,
which cancels exactly because the ADC reference (pin 15) is the same VEXC node (MCP3208 IREF <= 150 uA -> <= 33 mV).
ESD at J1: every force/ID line reaches the ADC through 3.3k into a 1 uF reservoir (8 kV HBM = 0.8 uC -> ~0.8 V step).
No TVS is fitted; the RC networks are the protection. System-level IEC 61000-4-2 testing is still required.
Divider output is NOT the Tekscan A201 op-amp reference circuit and does not inherit its linearity or drift figures.

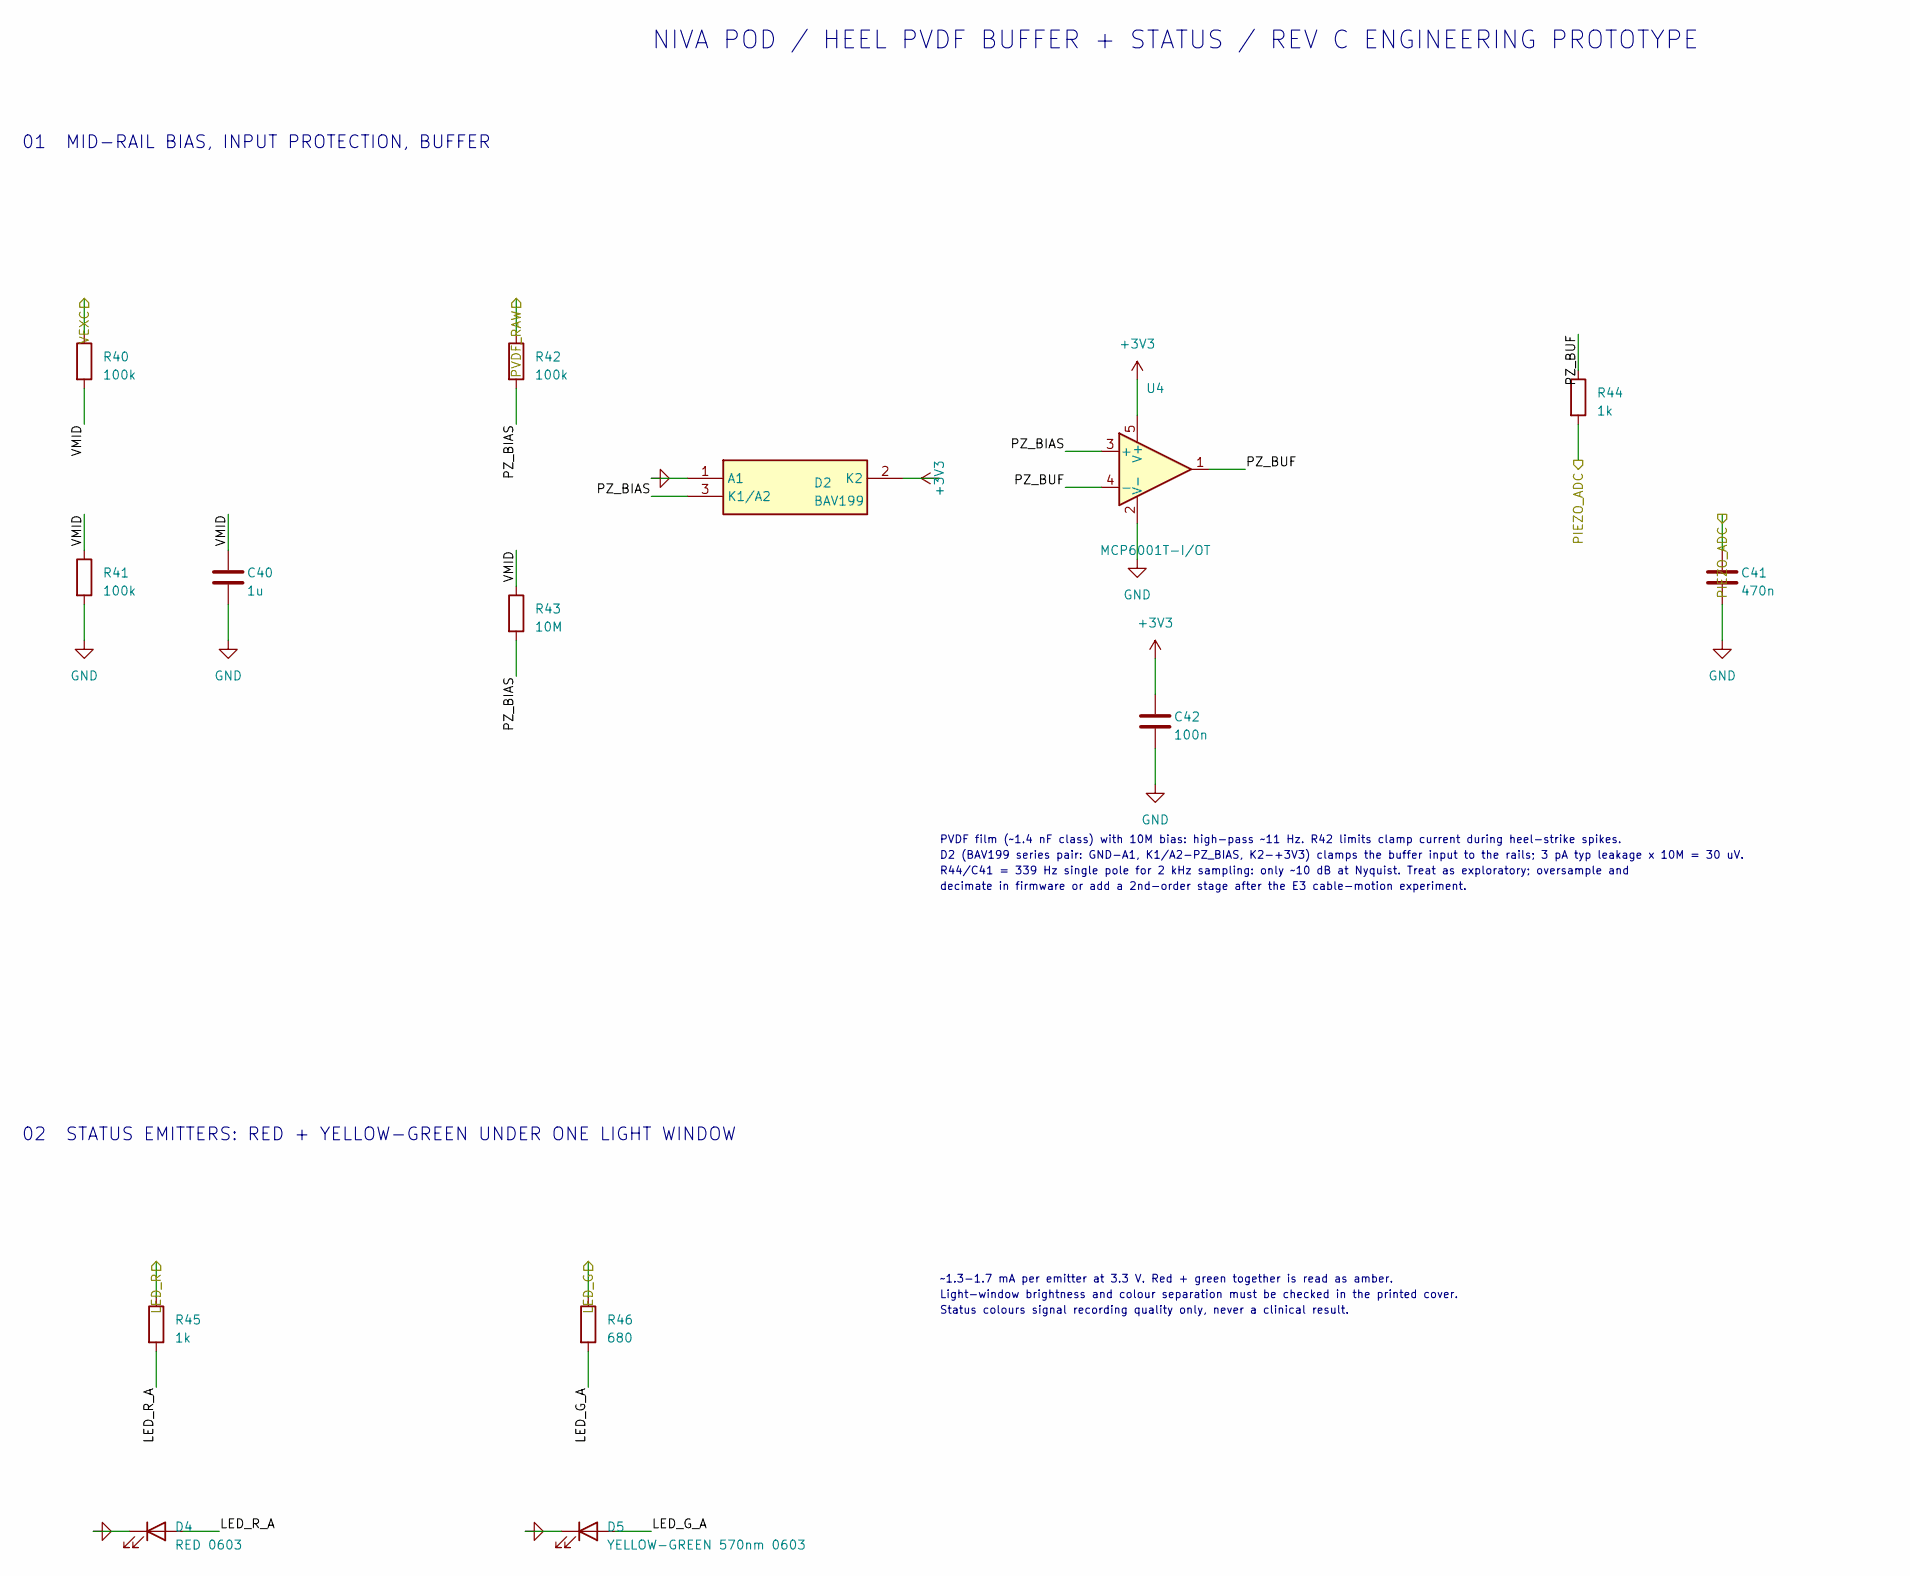
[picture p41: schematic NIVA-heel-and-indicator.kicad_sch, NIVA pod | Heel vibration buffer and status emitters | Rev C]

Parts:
C40: 1u; C_0603_1608Metric
C41: 470n; C_0603_1608Metric
C42: 100n; C_0603_1608Metric
D2: BAV199; SOT-23; MPN BAV199,215 (Nexperia) low-leakage serie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
D4: RED 0603; LED_0603_1608Metric
D5: YELLOW-GREEN 570nm 0603; LED_0603_1608Metric
R40, R41, R42: 100k; R_0603_1608Metric
R43: 10M; R_0603_1608Metric
R44, R45: 1k; R_0603_1608Metric
R46: 680; R_0603_1608Metric
U4: MCP6001T-I/OT; SOT-23-5; MPN MCP6001T-I/OT

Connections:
+3V3: C42.1, D2.2 (K2), U4.5 (V+); also elsewhere on the board
/Controller/LED_G: R46.1; also elsewhere on the board
/Controller/LED_R: R45.1; also elsewhere on the board
/Controller/PIEZO_ADC: C41.1, R44.2; also elsewhere on the board
/Controller/PVDF_RAW: R42.1; also elsewhere on the board
/Controller/VEXC: R40.1; also elsewhere on the board
/Heel and indicator/LED_G_A: D5.2 (A), R46.2
/Heel and indicator/LED_R_A: D4.2 (A), R45.2
/Heel and indicator/PZ_BIAS: D2.3 (K1/A2), R42.2, R43.2, U4.3 (+)
/Heel and indicator/PZ_BUF: R44.1, U4.1, U4.4 (-)
/Heel and indicator/VMID: C40.1, R40.2, R41.1, R43.1
GND: C40.2, C41.2, C42.2, D2.1 (A1), D4.1 (K), D5.1 (K), R41.2, U4.2 (V-); also elsewhere on the board

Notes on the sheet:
NIVA POD / HEEL PVDF BUFFER + STATUS / REV C ENGINEERING PROTOTYPE
01 MID-RAIL BIAS, INPUT PROTECTION, BUFFER
PVDF film (~1.4 nF class) with 10M bias: high-pass ~11 Hz. R42 limits clamp current during heel-strike spikes.
D2 (BAV199 series pair: GND-A1, K1/A2-PZ_BIAS, K2-+3V3) clamps the buffer input to the rails; 3 pA typ leakage x 10M = 30 uV.
R44/C41 = 339 Hz single pole for 2 kHz sampling: only ~10 dB at Nyquist. Treat as exploratory; oversample and
decimate in firmware or add a 2nd-order stage after the E3 cable-motion experiment.
02 STATUS EMITTERS: RED + YELLOW-GREEN UNDER ONE LIGHT WINDOW
~1.3-1.7 mA per emitter at 3.3 V. Red + green together is read as amber.
Light-window brightness and colour separation must be checked in the printed cover.
Status colours signal recording quality only, never a clinical result.

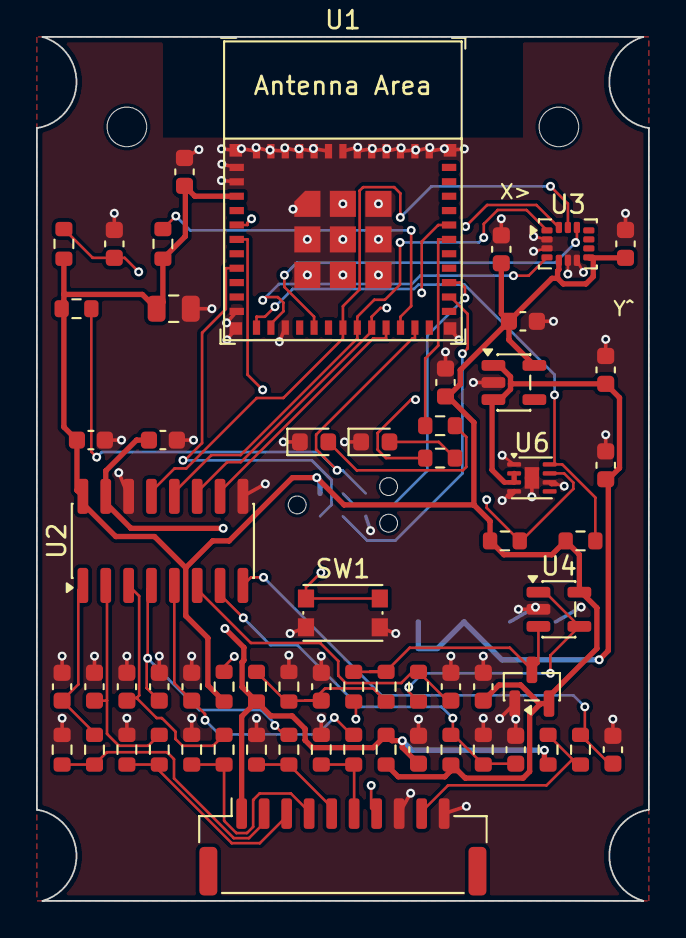
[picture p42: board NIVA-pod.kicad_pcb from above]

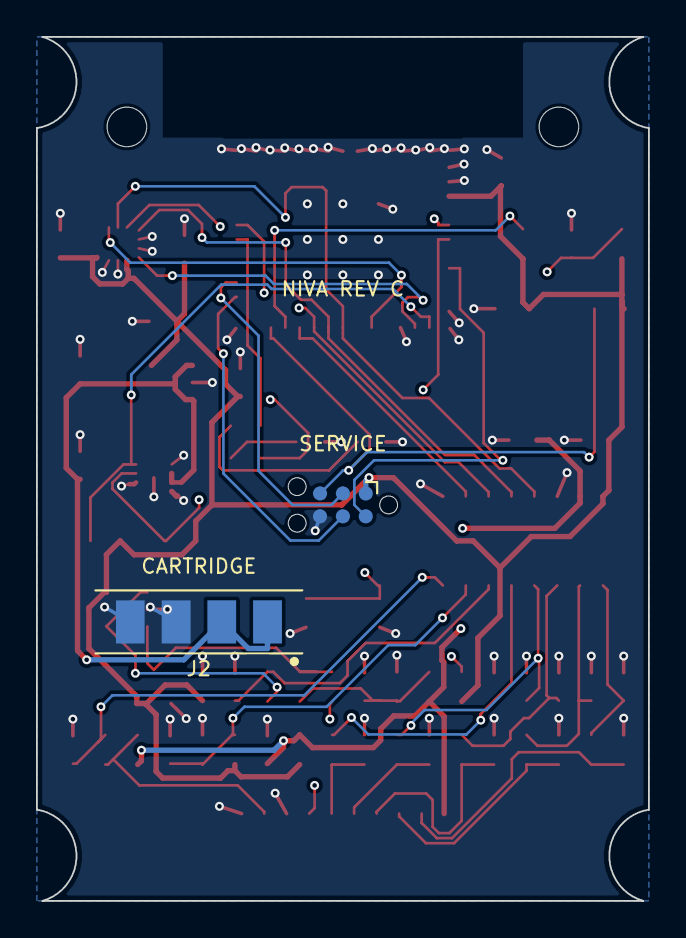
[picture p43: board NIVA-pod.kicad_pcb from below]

Board: 4 copper layers, 34.0 x 48.0 mm, 65 parts (2 on the bottom side), 40 nets.

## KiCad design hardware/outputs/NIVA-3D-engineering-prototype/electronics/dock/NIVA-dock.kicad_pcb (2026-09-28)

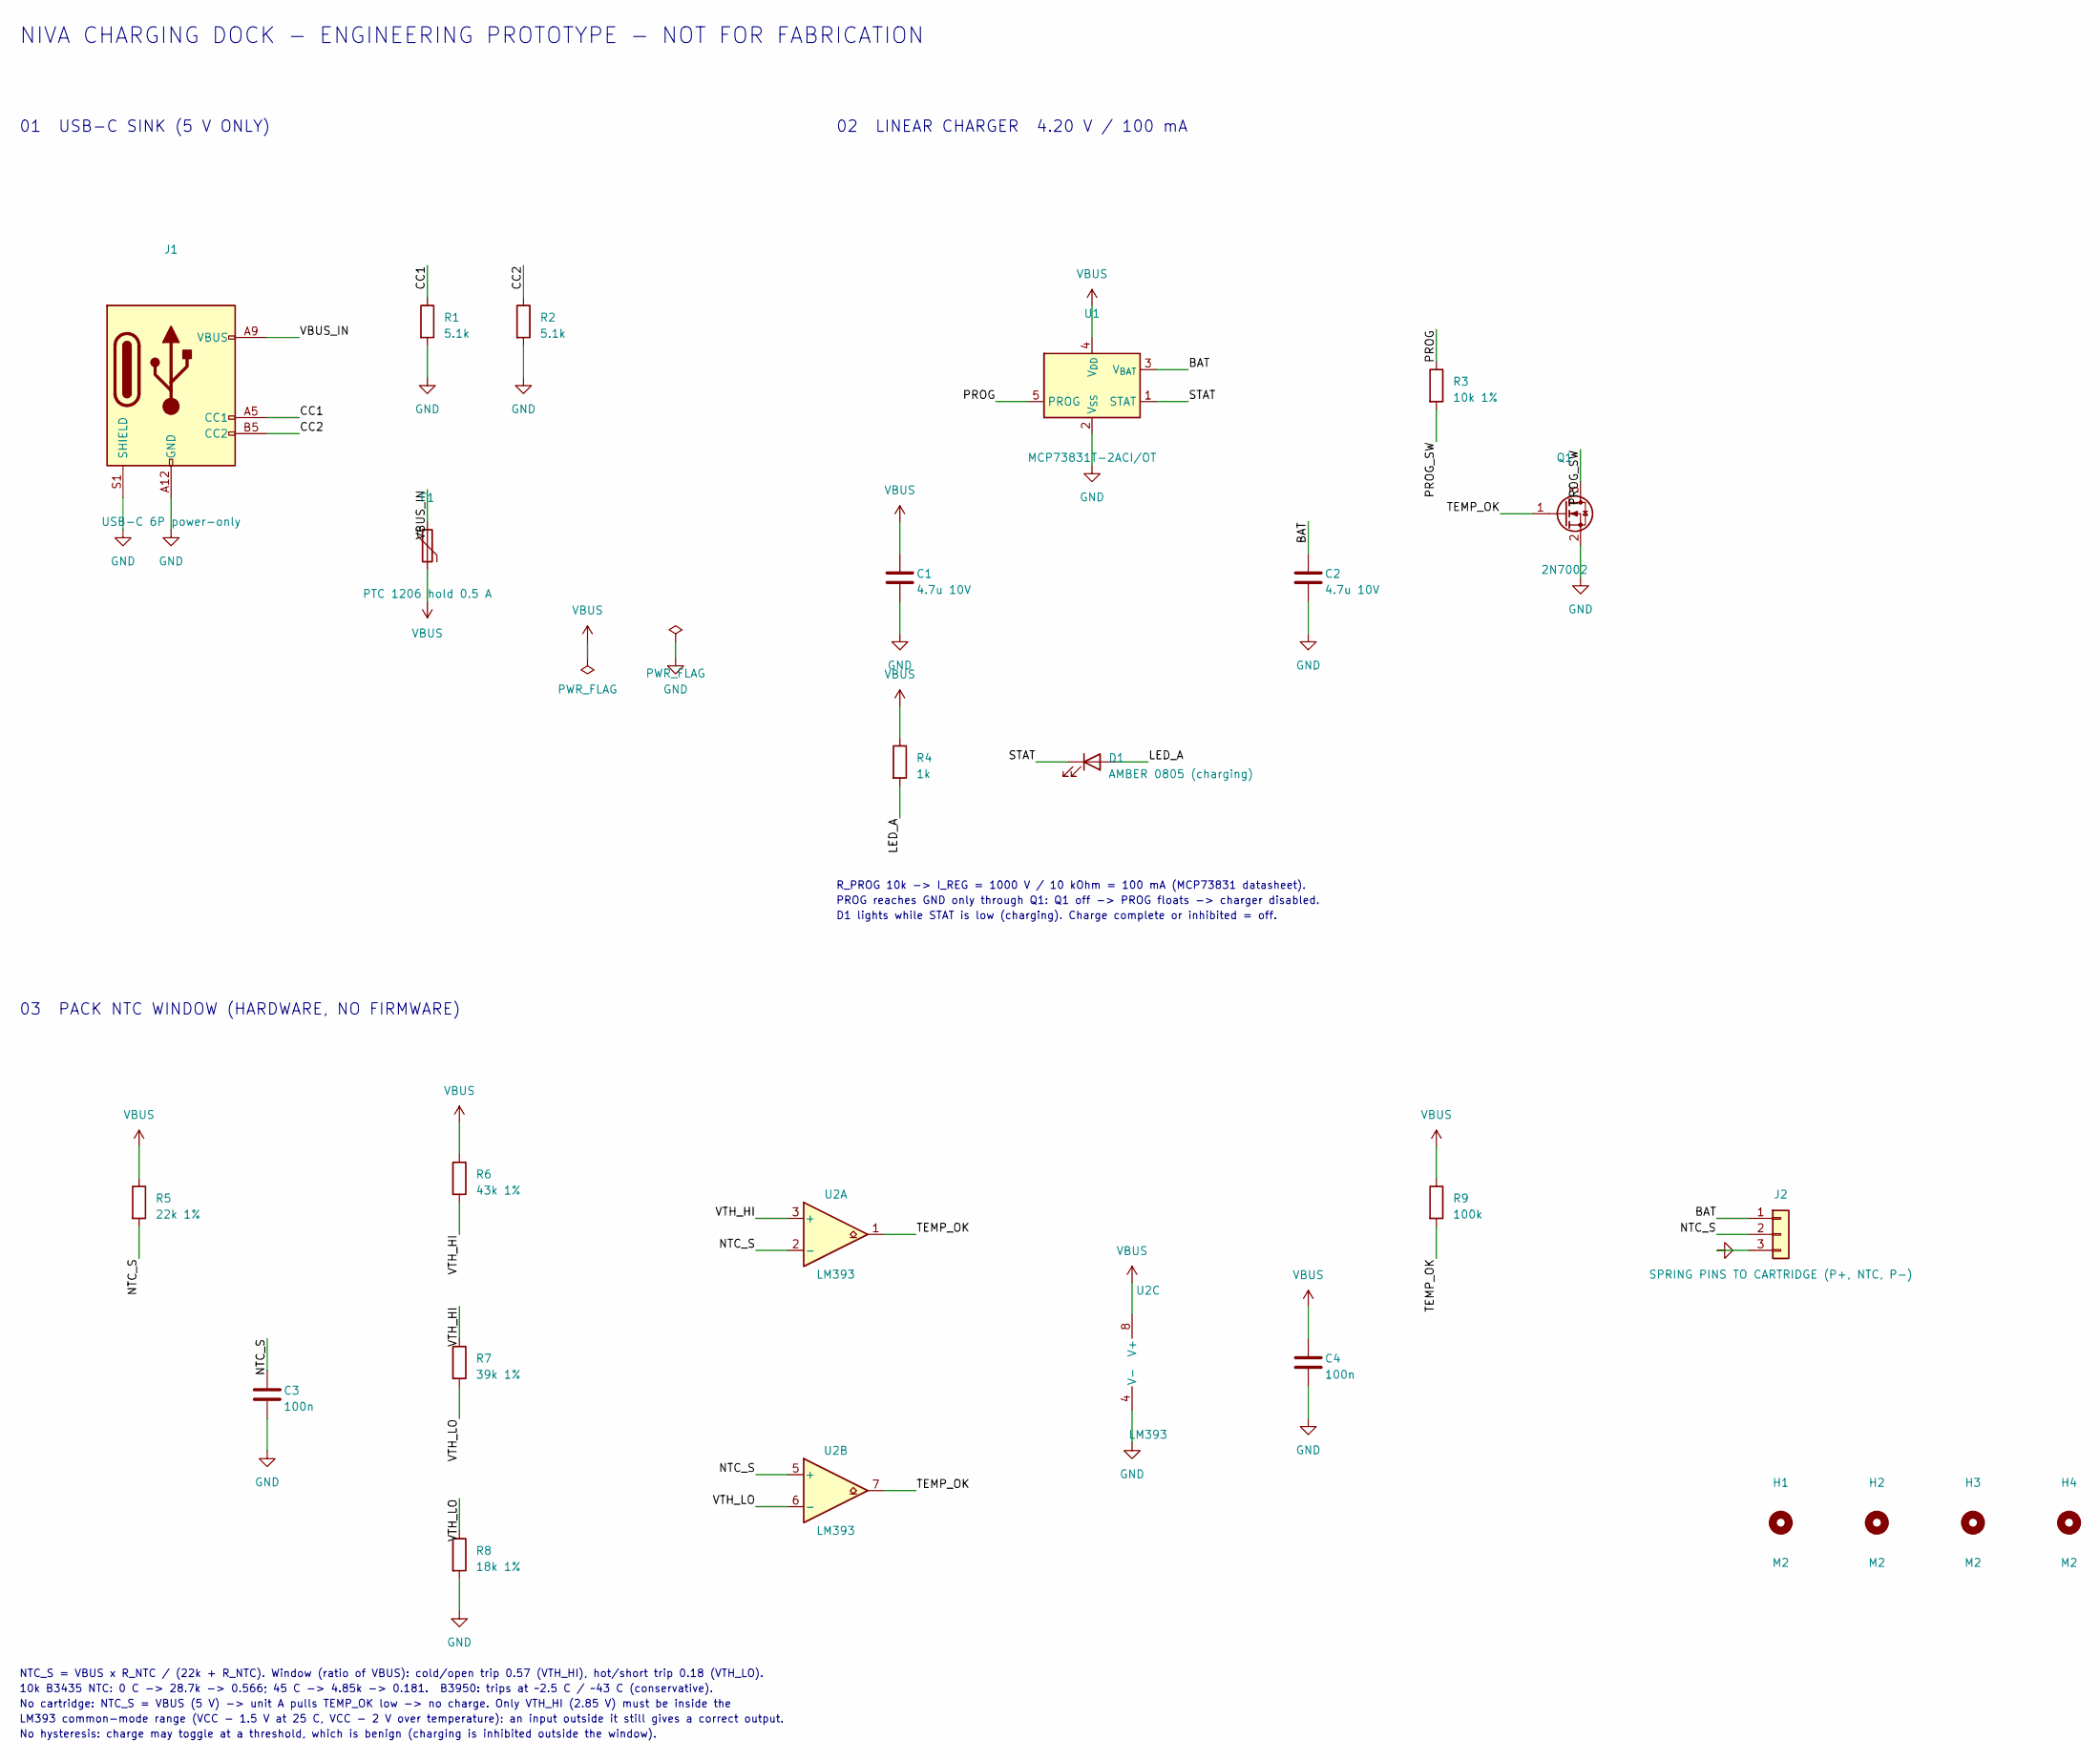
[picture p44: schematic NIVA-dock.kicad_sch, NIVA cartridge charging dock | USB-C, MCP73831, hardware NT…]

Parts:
C1, C2: 4.7u 10V; C_0603_1608Metric
C3, C4: 100n; C_0603_1608Metric
D1: AMBER 0805 (charging); LED_0805_2012Metric
F1: PTC 1206 hold 0.5 A; Fuse_1206_3216Metric
H1, H2, H3, H4: M2; MountingHole_2.2mm_M2
J1: USB-C 6P power-only; USB_C_Receptacle_GCT_USB4125-xx-x_6P_TopMnt_Horizontal; MPN GCT USB4125 class
J2: SPRING PINS TO CARTRIDGE (P+, NTC, P-); SpringPins_1x03_P6.0mm_Vertical
Q1: 2N7002; SOT-23
R1, R2: 5.1k; R_0603_1608Metric
R3: 10k 1%; R_0603_1608Metric
R4: 1k; R_0603_1608Metric
R5: 22k 1%; R_0603_1608Metric
R6: 43k 1%; R_0603_1608Metric
R7: 39k 1%; R_0603_1608Metric
R8: 18k 1%; R_0603_1608Metric
R9: 100k; R_0603_1608Metric
U1: MCP73831T-2ACI/OT; SOT-23-5; MPN MCP73831T-2ACI/OT
U2: LM393; SOIC-8_3.9x4.9mm_P1.27mm

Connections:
/BAT: C2.1, J2.1, U1.3 (V_{BAT})
/CC1: J1.A5 (CC1), R1.1
/CC2: J1.B5 (CC2), R2.1
/LED_A: D1.2 (A), R4.2
/NTC_S: C3.1, J2.2, R5.2, U2.2 (-), U2.5 (+)
/PROG: R3.1, U1.5 (PROG)
/PROG_SW: Q1.3 (D), R3.2
/STAT: D1.1 (K), U1.1 (STAT)
/TEMP_OK: Q1.1 (G), R9.2, U2.1, U2.7
/VBUS_IN: F1.1, J1.A9 (VBUS), J1.B9 (VBUS)
/VTH_HI: R6.2, R7.1, U2.3 (+)
/VTH_LO: R7.2, R8.1, U2.6 (-)
GND: C1.2, C2.2, C3.2, C4.2, J1.A12 (GND), J1.B12 (GND), J1.S1 (SHIELD), J2.3, Q1.2 (S), R1.2, R2.2, R8.2, U1.2 (V_{SS}), U2.4 (V-)
VBUS: C1.1, C4.1, F1.2, R4.1, R5.1, R6.1, R9.1, U1.4 (V_{DD}), U2.8 (V+)

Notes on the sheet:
NIVA CHARGING DOCK - ENGINEERING PROTOTYPE - NOT FOR FABRICATION
01 USB-C SINK (5 V ONLY)
02 LINEAR CHARGER 4.20 V / 100 mA
R_PROG 10k -> I_REG = 1000 V / 10 kOhm = 100 mA (MCP73831 datasheet).
PROG reaches GND only through Q1: Q1 off -> PROG floats -> charger disabled.
D1 lights while STAT is low (charging). Charge complete or inhibited = off.
03 PACK NTC WINDOW (HARDWARE, NO FIRMWARE)
NTC_S = VBUS x R_NTC / (22k + R_NTC). Window (ratio of VBUS): cold/open trip 0.57 (VTH_HI), hot/short trip 0.18 (VTH_LO).
10k B3435 NTC: 0 C -> 28.7k -> 0.566; 45 C -> 4.85k -> 0.181. B3950: trips at ~2.5 C / ~43 C (conservative).
No cartridge: NTC_S = VBUS (5 V) -> unit A pulls TEMP_OK low -> no charge. Only VTH_HI (2.85 V) must be inside the
LM393 common-mode range (VCC - 1.5 V at 25 C, VCC - 2 V over temperature): an input outside it still gives a correct output.
No hysteresis: charge may toggle at a threshold, which is benign (charging is inhibited outside the window).

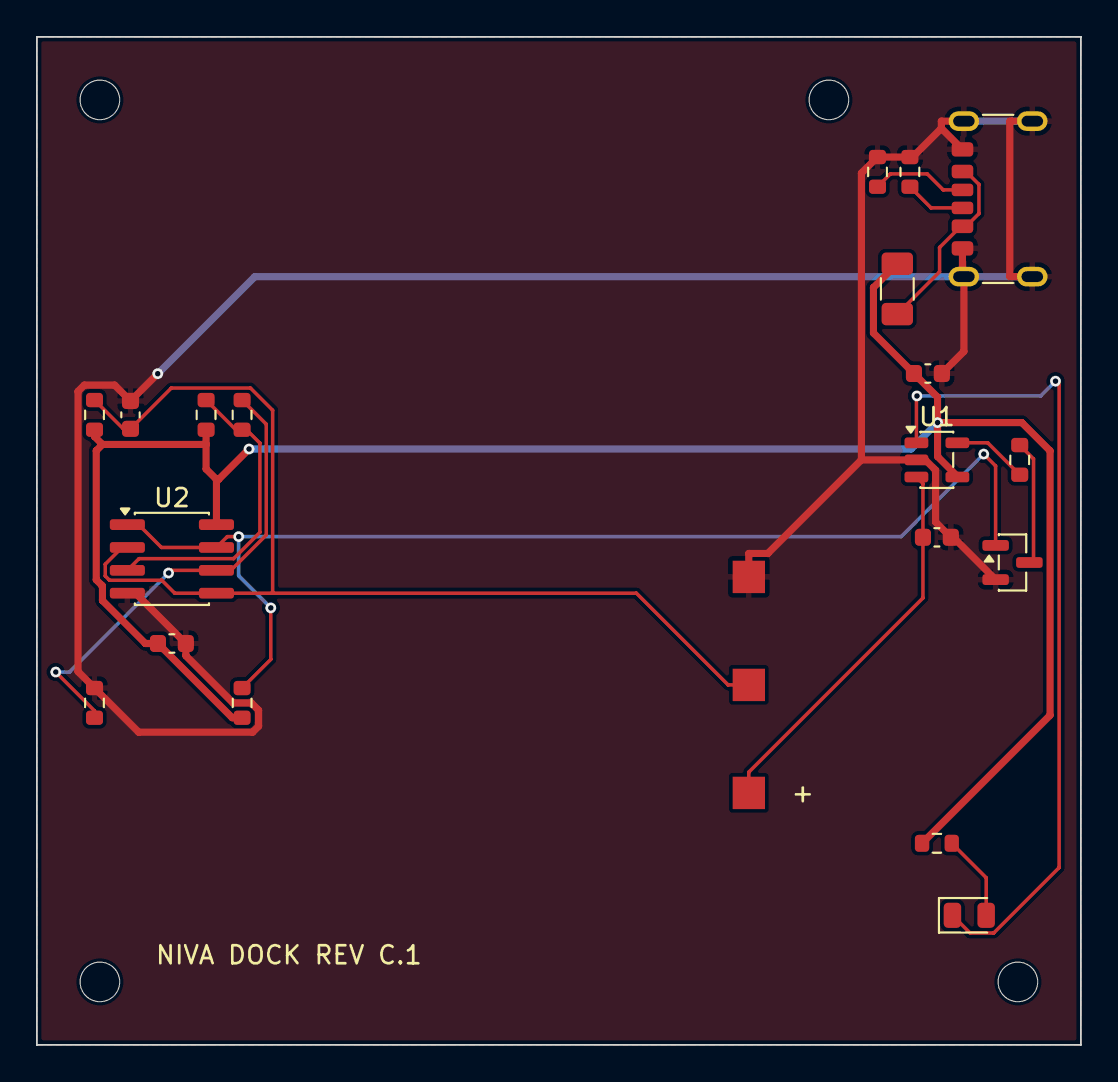
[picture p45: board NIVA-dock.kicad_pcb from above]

Board: 2 copper layers, 58.0 x 56.0 mm, 24 parts (0 on the bottom side), 14 nets.

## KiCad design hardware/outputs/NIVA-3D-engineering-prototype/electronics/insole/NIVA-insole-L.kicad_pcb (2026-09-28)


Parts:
FSR1: P1 Big toe (shunt FSR, 12 mm); FSR_Interdigitated_D12mm
FSR2: P2 Medial forefoot (shunt FSR, 12 mm); FSR_Interdigitated_D12mm
FSR3: P3 Lateral forefoot (shunt FSR, 12 mm); FSR_Interdigitated_D12mm
FSR4: P4 Lateral midfoot (shunt FSR, 12 mm); FSR_Interdigitated_D12mm
FSR5: P5 Heel (shunt FSR, 12 mm); FSR_Interdigitated_D12mm
J1: CABLE TO POD J1 (JST GH 10); WirePads_1x10_P2.0mm_LaneOrder
J2: V1 PVDF FILM (signal, return); PVDF_BondPads_2x6x2mm
R1: 47k 0.1%; R_0603_1608Metric; MPN 0603 thin film 47k 0.1% (left medium co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

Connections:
/F1_RAW: FSR1.1, J1.2
/F2_RAW: FSR2.1, J1.3
/F3_RAW: FSR3.1, J1.4
/F4_RAW: FSR4.1, J1.5
/F5_RAW: FSR5.1, J1.6
/INSERT_ID_RAW: J1.9, R1.2
/PVDF_RAW: J1.7, J2.1
/VEXC: FSR1.2, FSR2.2, FSR3.2, FSR4.2, FSR5.2, J1.1
GND: J1.8, J1.10, J2.2, R1.1

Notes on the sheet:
NIVA SENSING INSOLE FLEX - LEFT MEDIUM - ENGINEERING PROTOTYPE - NOT FOR FABRICATION
Each FSRn: drive comb to VEXC (pod excitation), sense comb to Fn_RAW (pod load resistor + filter to MCP3208, ratiometric).
Five separate drive leads underfoot, joined to VEXC only at the above-collar transition (B.Cu) - no crossings underfoot.
R1 insert ID: V(ID) = VEXC x R1 / (10k + R1) with pod R30 = 10k 0.1 %. 47k 0.1% = left medium.
Right-medium 4.7k -> 0.320; left-medium 47k -> 0.825 of VEXC. The app must refuse a mismatched side.
FSR response depends on the FSR ink film, spacer and lamination: characterise before any use of the numbers.


Board: 2 copper layers, 217.5 x 234.0 mm, 8 parts (0 on the bottom side), 9 nets.

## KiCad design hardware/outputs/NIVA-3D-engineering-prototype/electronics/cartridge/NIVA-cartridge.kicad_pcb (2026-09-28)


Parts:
F1: PTC 0805 hold>=0.5 A, >=6 V; Fuse_0805_2012Metric; MPN to select (e.g. 0805 resettable, I_hold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
J1: CELL LEADS (+, NTC, -); WirePads_1x03_P1.8mm
J2: TO LID PLATES (P-, P-, P+, P+) -> pod J2; WirePads_1x04_P1.7mm
J3: DOCK PADS (P+, NTC, P-), underside; ContactPads_1x03_P6.0mm

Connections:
/CELL_P: F1.1, J1.1
/NTC: J1.2, J3.2
/PACK_N: J1.3, J2.1, J2.2, J3.3
/PACK_P: F1.2, J2.3, J2.4, J3.1

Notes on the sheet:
NIVA CARTRIDGE INTERCONNECT - ENGINEERING PROTOTYPE - NOT FOR FABRICATION
Cell: EEMB LP502030 class with integrated protection module (OV/UV/OC/short) and NTC lead - protection layer 1.
F1 polyfuse in series with every external P+ path (pod and dock) - independent protection layer 2.
NTC is passed to the dock only; the pod never sees it. No active parts in the cartridge.
Dock pads are exposed only on the cartridge rear face, which the cradle covers while the pod is worn.


Board: 2 copper layers, 3.4 x 30.0 mm, 4 parts (1 on the bottom side), 4 nets.

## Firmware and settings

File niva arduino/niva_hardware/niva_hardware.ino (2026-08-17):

// GaitGuard Nexus firmware + SH1106 OLED status display
//
// NIVA GaitGuard ESP32 sketch — WiFiManager captive-portal WiFi setup, a
// real MPU6050 IMU feeding pitch/roll/accZ, NVS-persisted FSR baselines,
// mDNS (ws://niva.local:81), and oversampled ADC reads — with a 1.3" I2C
// OLED (SH1106 driver, confirmed via I2C scan at address 0x3C) added on
// top, showing boot status, WiFi/captive-portal state, calibration
// progress, and a live per-channel bar readout once the insole is
// streaming. Everything else is unchanged.
//
// The OLED shares the same I2C bus as the MPU6050 (SDA=21, SCL=22) at a
// different address, so no extra wiring is needed beyond the display itself.
//
// Requires:
//   - WiFiManager by tzapu (https://github.com/tzapu/WiFiManager)
//   - U8g2 by olikraus (Library Manager -> search "U8g2")

#include <WiFi.h>
#include <WebSocketsServer.h>
#include <WiFiManager.h>      // WiFiManager by tzapu (https://github.com/tzapu/WiFiManager)
#include <ESPmDNS.h>
#include <Wire.h>
#include <Preferences.h>
#include <U8g2lib.h>          // U8g2 by olikraus (Library Manager -> search "U8g2")

// -----------------------------------------------------------------------------
// Hardware Pin Map (NIVA GaitGuard Nexus Spec)
// -----------------------------------------------------------------------------
static const int PIN_HEEL   = 32; // FSR Heel (ADC1_CH4)
static const int PIN_INNER  = 33; // FSR Inner / MT1 (ADC1_CH5)
static const int PIN_OUTER  = 34; // FSR Outer / MT5 (ADC1_CH6)
static const int PIN_TOE    = 35; // FSR Toe (ADC1_CH7)
static const int PIN_PIEZO  = 36; // Piezo Heel Disc (ADC1_CH0 / SENSOR_VP)

static const int PIN_SDA    = 21; // Shared I2C bus: MPU6050 (0x68) + OLED (0x3C)
static const int PIN_SCL    = 22;
static const int PIN_LED    = 2;  // Onboard Status LED

// -----------------------------------------------------------------------------
// Configuration Constants
// -----------------------------------------------------------------------------
static const unsigned long STREAM_INTERVAL_MS = 50;  // 20Hz telemetry stream interval
static const uint16_t CALIBRATION_SAMPLES = 60;      // Baseline tare sample count
static const uint8_t ADC_OVERSAMPLE_COUNT = 16;      // Oversampling iterations per channel
static const uint16_t WS_PORT = 81;                  // WebSocket server port
static const int MPU6050_ADDR = 0x68;                 // MPU6050 default I2C address

// Redrawn on its own slower clock so a full 128x64 I2C frame write never
// competes with the 50ms sensor/WebSocket cadence above.
static const unsigned long DISPLAY_INTERVAL_MS = 200;

// Reference ceiling used only to scale the on-screen bar graphs (0..this
// maps to an empty..full bar). Matches the dashboard's own impact-scaling
// reference (`maxImpact: 800`) so the bars roughly agree with what the app
// would call "high" — it isn't a calibration value, just a display scale.
static const float DISPLAY_BAR_MAX = 800.0f;

// -----------------------------------------------------------------------------
// Global Objects & State Variables
// -----------------------------------------------------------------------------
WebSocketsServer wsServer(WS_PORT);
Preferences preferences;

// Full-buffer, hardware I2C SH1106 driver. If your panel turns out to be
// SSD1306 instead (see the fallback note at the bottom of this file), swap
// this one line and nothing else needs to change.
U8G2_SH1106_128X64_NONAME_F_HW_I2C u8g2(U8G2_R0, U8X8_PIN_NONE);

struct SensorBaselines {
  float heel = 0.0f;
  float inner = 0.0f;
  float outer = 0.0f;
  float toe = 0.0f;
  float piezo = 0.0f;
} baselines;

bool isCalibrated = false;
bool mpuAvailable = false;
uint16_t calibrationCount = 0;
float calAccumHeel = 0.0f, calAccumInner = 0.0f, calAccumOuter = 0.0f, calAccumToe = 0.0f, calAccumPiezo = 0.0f;

// Kinematics (MPU6050 IMU)
float pitchDeg = 0.0f;
float rollDeg = 0.0f;
float accZ = 9.81f; // m/s^2
unsigned long lastKinematicsUpdate = 0;

// Cached post-baseline channel values so the display loop can redraw at its
// own cadence without re-reading the ADCs itself.
float lastHeel = 0.0f;
float lastInner = 0.0f;
float lastOuter = 0.0f;
float lastToe = 0.0f;
float lastPiezo = 0.0f;

// Timing
unsigned long lastStreamAt = 0;
unsigned long lastDisplayAt = 0;

// -----------------------------------------------------------------------------
// Function Prototypes
// -----------------------------------------------------------------------------
void initMPU6050();
void updateKinematics();
float oversampleADC(int pin);
void performCalibrationStep(float rawH, float rawI, float rawO, float rawT, float rawP);
void saveBaselinesToNVS();
void loadBaselinesFromNVS();
void handleWebSocketEvent(uint8_t num, WStype_t type, uint8_t * payload, size_t length);
void handleIncomingCommand(const String& cmd);

// -----------------------------------------------------------------------------
// Display Helpers
// -----------------------------------------------------------------------------
void showBootScreen() {
  u8g2.clearBuffer();
  u8g2.setFont(u8g2_font_ncenB10_tr);
  u8g2.drawStr(6, 22, "GaitGuard Nexus");
  u8g2.setFont(u8g2_font_6x10_tf);
  u8g2.drawStr(6, 40, "Booting...");
  u8g2.sendBuffer();
}

void showWiFiPortalActive() {
  u8g2.clearBuffer();
  u8g2.setFont(u8g2_font_ncenB10_tr);
  u8g2.drawStr(6, 22, "GaitGuard Nexus");
  u8g2.setFont(u8g2_font_6x10_tf);
  u8g2.drawStr(6, 38, "Setup WiFi at:");
  u8g2.drawStr(6, 52, "NIVA-GaitGuard-AP");
  u8g2.sendBuffer();
}

void showWiFiResult(bool connected) {
  u8g2.clearBuffer();
  u8g2.setFont(u8g2_font_ncenB10_tr);
  u8g2.drawStr(6, 22, "GaitGuard Nexus");
  u8g2.setFont(u8g2_font_6x10_tf);

  if (connected) {
    u8g2.drawStr(6, 38, "WiFi connected");
    char ipLine[24];
    snprintf(ipLine, sizeof(ipLine), "IP %s", WiFi.localIP().toString().c_str());
    u8g2.drawStr(6, 52, ipLine);
  } else {
    u8g2.drawStr(6, 38, "Setup timed out");
    u8g2.drawStr(6, 52, "Offline AP mode");
  }
  u8g2.sendBuffer();
  delay(1200); // let the result be readable before the calibration screen takes over
}

void showCalibrating(uint16_t count, uint16_t total) {
  u8g2.clearBuffer();
  u8g2.setFont(u8g2_font_6x10_tf);
  u8g2.drawStr(6, 12, "Calibrating...");
  u8g2.drawStr(6, 26, "Keep foot unloaded");

  // Progress bar.
  const int barX = 6;
  const int barY = 36;
  const int barW = 116;
  const int barH = 10;
  u8g2.drawFrame(barX, barY, barW, barH);
  int fillW = (int)((float)count / (float)total * (barW - 2));
  if (fillW > barW - 2) fillW = barW - 2;
  if (fillW > 0) u8g2.drawBox(barX + 1, barY + 1, fillW, barH - 2);

  char countLine[16];
  snprintf(countLine, sizeof(countLine), "%u / %u", count, total);
  u8g2.drawStr(6, 60, countLine);

  u8g2.sendBuffer();
}

// One labeled horizontal bar: "H |####------|"
void drawChannelBar(int y, const char* label, float value) {
  u8g2.setFont(u8g2_font_5x8_tf);
  u8g2.drawStr(0, y + 7, label);

  const int barX = 12;
  const int barW = 100;
  const int barH = 8;
  u8g2.drawFrame(barX, y, barW, barH);

  float clamped = value;
  if (clamped < 0) clamped = 0;
  if (clamped > DISPLAY_BAR_MAX) clamped = DISPLAY_BAR_MAX;

  int fillW = (int)((clamped / DISPLAY_BAR_MAX) * (barW - 2));
  if (fillW > 0) u8g2.drawBox(barX + 1, y + 1, fillW, barH - 2);
}

void showLiveReadout(bool wifiConnected) {
  u8g2.clearBuffer();
  u8g2.setFont(u8g2_font_5x8_tf);
  u8g2.drawStr(0, 7, wifiConnected ? "WiFi OK" : "WiFi --");
  u8g2.drawStr(70, 7, mpuAvailable ? "IMU OK" : "IMU --");

  drawChannelBar(11, "H", lastHeel);
  drawChannelBar(21, "I", lastInner);
  drawChannelBar(31, "O", lastOuter);
  drawChannelBar(41, "T", lastToe);
  drawChannelBar(51, "P", lastPiezo);

  u8g2.sendBuffer();
}

// -----------------------------------------------------------------------------
// MPU6050 Wire-based Kinematics Processing
// -----------------------------------------------------------------------------
void initMPU6050() {
  // Wire.begin() is already called in setup() so the OLED and IMU can share
  // the same hardware I2C bus.
  Wire.beginTransmission(MPU6050_ADDR);
  Wire.write(0x6B); // PWR_MGMT_1 register
  Wire.write(0x00); // Wake up MPU6050
  if (Wire.endTransmission() == 0) {
    mpuAvailable = true;
    Serial.println("[IMU] MPU6050 initialized successfully at 0x68");
  } else {
    mpuAvailable = false;
    Serial.println("[IMU] WARNING: MPU6050 not detected at 0x68. Kinematics set to fallback (0.0).");
  }
}

void updateKinematics() {
  if (!mpuAvailable) {
    pitchDeg = 0.0f;
    rollDeg = 0.0f;
    accZ = 0.0f;
    return;
  }

  Wire.beginTransmission(MPU6050_ADDR);
  Wire.write(0x3B); // ACCEL_XOUT_H
  if (Wire.endTransmission(false) != 0) return;

  if (Wire.requestFrom(MPU6050_ADDR, 14, true) == 14) {
    int16_t axRaw = (Wire.read() << 8) | Wire.read();
    int16_t ayRaw = (Wire.read() << 8) | Wire.read();
    int16_t azRaw = (Wire.read() << 8) | Wire.read();
    Wire.read(); Wire.read(); // Skip temp bytes
    int16_t gxRaw = (Wire.read() << 8) | Wire.read();
    int16_t gyRaw = (Wire.read() << 8) | Wire.read();
    int16_t gzRaw = (Wire.read() << 8) | Wire.read();

    float ax = axRaw / 16384.0f; // Scale factor for +/-2g
    float ay = ayRaw / 16384.0f;
    float az = azRaw / 16384.0f;

    float gx = gxRaw / 131.0f; // Scale factor for +/-250 deg/s
    float gy = gyRaw / 131.0f;

    // Calculate Accelerometer Angles
    float accelPitch = atan2(-ax, sqrt(ay * ay + az * az)) * 180.0f / M_PI;
    float accelRoll  = atan2(ay, az) * 180.0f / M_PI;

    // Complementary Filter Fusion (96% Gyro, 4% Accel)
    unsigned long now = millis();
    float dt = (now - lastKinematicsUpdate) / 1000.0f;
    if (dt <= 0.0f || dt > 0.5f) dt = 0.01f;
    lastKinematicsUpdate = now;

    pitchDeg = 0.96f * (pitchDeg + gy * dt) + 0.04f * accelPitch;
    rollDeg  = 0.96f * (rollDeg + gx * dt) + 0.04f * accelRoll;
    accZ     = az * 9.81f; // Convert g to m/s^2
  }
}

// -----------------------------------------------------------------------------
// Low-Noise Oversampled Analog Read
// -----------------------------------------------------------------------------
float oversampleADC(int pin) {
  uint32_t sum = 0;
  for (uint8_t i = 0; i < ADC_OVERSAMPLE_COUNT; i++) {
    sum += analogRead(pin);
  }
  return static_cast<float>(sum) / ADC_OVERSAMPLE_COUNT;
}

// -----------------------------------------------------------------------------
// Calibration Logic & Non-Volatile Storage (NVS)
// -----------------------------------------------------------------------------
void performCalibrationStep(float rawH, float rawI, float rawO, float rawT, float rawP) {
  calibrationCount++;
  calAccumHeel  += rawH;
  calAccumInner += rawI;
  calAccumOuter += rawO;
  calAccumToe   += rawT;
  calAccumPiezo += rawP;

  // Toggle status LED during calibration phase
  digitalWrite(PIN_LED, (calibrationCount % 2 == 0) ? HIGH : LOW);

  if (calibrationCount >= CALIBRATION_SAMPLES) {
    baselines.heel  = calAccumHeel  / CALIBRATION_SAMPLES;
    baselines.inner = calAccumInner / CALIBRATION_SAMPLES;
    baselines.outer = calAccumOuter / CALIBRATION_SAMPLES;
    baselines.toe   = calAccumToe   / CALIBRATION_SAMPLES;
    baselines.piezo = calAccumPiezo / CALIBRATION_SAMPLES;

    isCalibrated = true;
    saveBaselinesToNVS();

    Serial.println("[CALIBRATION] Tare Baseline Complete!");
    Serial.printf("[CALIBRATION] Baselines -> Heel:%.1f, Inner:%.1f, Outer:%.1f, Toe:%.1f, Piezo:%.1f\n",
                  baselines.heel, baselines.inner, baselines.outer, baselines.toe, baselines.piezo);
    digitalWrite(PIN_LED, HIGH);
  }
}

void saveBaselinesToNVS() {
  preferences.begin("gaitguard", false);
  preferences.putFloat("b_heel", baselines.heel);
  preferences.putFloat("b_inner", baselines.inner);
  preferences.putFloat("b_outer", baselines.outer);
  preferences.putFloat("b_toe", baselines.toe);
  preferences.putFloat("b_piezo", baselines.piezo);
  preferences.putBool("calibrated", true);
  preferences.end();
}

void loadBaselinesFromNVS() {
  preferences.begin("gaitguard", true);
  bool saved = preferences.getBool("calibrated", false);
  if (saved) {
    baselines.heel  = preferences.getFloat("b_heel", 0.0f);
    baselines.inner = preferences.getFloat("b_inner", 0.0f);
    baselines.outer = preferences.getFloat("b_outer", 0.0f);
    baselines.toe   = preferences.getFloat("b_toe", 0.0f);
    baselines.piezo = preferences.getFloat("b_piezo", 0.0f);
    isCalibrated = true;
    Serial.println("[NVS] Loaded saved tare baselines from Flash storage.");
  }
  preferences.end();
}

// -----------------------------------------------------------------------------
// WebSocket Event & Interactive Command Handlers
// -----------------------------------------------------------------------------
void handleWebSocketEvent(uint8_t num, WStype_t type, uint8_t * payload, size_t length) {
  if (type == WStype_TEXT) {
    String cmd = String((char*)payload);
    cmd.trim();
    Serial.printf("[WS] Client #%u sent command: %s\n", num, cmd.c_str());
    handleIncomingCommand(cmd);
  } else if (type == WStype_CONNECTED) {
    IPAddress ip = wsServer.remoteIP(num);
    Serial.printf("[WS] Client #%u connected from %d.%d.%d.%d\n", num, ip[0], ip[1], ip[2], ip[3]);
  }
}

void handleIncomingCommand(const String& cmd) {
  if (cmd.equalsIgnoreCase("calibrate") || cmd.equalsIgnoreCase("tare") || cmd.indexOf("calibrate") >= 0) {
    Serial.println("[CMD] Initiating runtime FSR re-tare...");
    isCalibrated = false;
    calibrationCount = 0;
    calAccumHeel = calAccumInner = calAccumOuter = calAccumToe = calAccumPiezo = 0.0f;
  }
}

// -----------------------------------------------------------------------------
// Main Setup and Execution Loop
// -----------------------------------------------------------------------------
void setup() {
  Serial.begin(115200);
  delay(300);

  // Bring the I2C bus up first (shared by the OLED and MPU6050) so the boot
  // screen can show immediately.
  Wire.begin(PIN_SDA, PIN_SCL, 400000); // 400kHz Fast I2C
  u8g2.begin();
  showBootScreen();

  pinMode(PIN_LED, OUTPUT);
  digitalWrite(PIN_LED, LOW);

  analogReadResolution(12);
  analogSetAttenuation(ADC_11db); // Full 0-3.3V range

  pinMode(PIN_HEEL, INPUT);
  pinMode(PIN_INNER, INPUT);
  pinMode(PIN_OUTER, INPUT);
  pinMode(PIN_TOE, INPUT);
  pinMode(PIN_PIEZO, INPUT);

  // Initialize IMU
  initMPU6050();

  // Restore saved baselines from Flash NVS if present
  loadBaselinesFromNVS();

  // WiFiManager captive portal
  WiFiManager wm;
  wm.setConfigPortalTimeout(180); // 3-minute AP timeout before proceeding
  wm.setAPCallback([](WiFiManager *myWM) {
    Serial.println("[WIFI] Captive Portal Active! Connect phone to AP: NIVA-GaitGuard-AP (IP: 192.168.4.1)");
    showWiFiPortalActive();
  });

  Serial.println("[WIFI] Connecting to WiFi...");
  bool res = wm.autoConnect("NIVA-GaitGuard-AP", "gaitguard123");

  if (!res) {
    Serial.println("[WIFI] WiFi setup timed out. Proceeding in offline AP fallback mode.");
  } else {
    Serial.println("[WIFI] WiFi Connected Successfully!");
    Serial.print("[WIFI] ESP32 Local IP: ");
    Serial.println(WiFi.localIP());
  }
  showWiFiResult(res);

  // Setup mDNS hostnames (ws://niva.local:81 and ws://gaitguard.local:81)
  if (MDNS.begin("niva")) {
    MDNS.addService("ws", "tcp", WS_PORT);
    Serial.println("[mDNS] Hostname registered: ws://niva.local:81");
  }
  if (MDNS.begin("gaitguard")) {
    MDNS.addService("ws", "tcp", WS_PORT);
  }

  // Start WebSocket Server
  wsServer.begin();
  wsServer.onEvent(handleWebSocketEvent);

  Serial.println("[SYSTEM] NIVA GaitGuard ESP32 System Ready!");
}

void loop() {
  wsServer.loop();
  updateKinematics();

  // Check incoming Serial commands
  if (Serial.available()) {
    String serialCmd = Serial.readStringUntil('\n');
    handleIncomingCommand(serialCmd);
  }

  unsigned long now = millis();
  if (now - lastStreamAt < STREAM_INTERVAL_MS) {
    // Still let the display redraw on its own cadence even on ticks where
    // we skip sensor sampling, so WiFi/IMU status changes show up promptly.
    if (now - lastDisplayAt >= DISPLAY_INTERVAL_MS) {
      lastDisplayAt = now;
      if (isCalibrated) {
        showLiveReadout(WiFi.status() == WL_CONNECTED);
      } else {
        showCalibrating(calibrationCount, CALIBRATION_SAMPLES);
      }
    }
    return;
  }
  lastStreamAt = now;

  // Read oversampled ADC values
  float rawHeel  = oversampleADC(PIN_HEEL);
  float rawInner = oversampleADC(PIN_INNER);
  float rawOuter = oversampleADC(PIN_OUTER);
  float rawToe   = oversampleADC(PIN_TOE);
  float rawPiezo = oversampleADC(PIN_PIEZO);

  if (!isCalibrated) {
    performCalibrationStep(rawHeel, rawInner, rawOuter, rawToe, rawPiezo);

    // Send zero telemetry frame during tare phase
    const char* calPacket = "{\"heel\":0,\"inner\":0,\"outer\":0,\"toe\":0,\"piezo\":0,\"pitch\":0,\"roll\":0,\"accZ\":0}";
    wsServer.broadcastTXT(calPacket);
    Serial.println("CALIBRATING,0,0,0,0,0,0,0,0");
    return;
  }

  // Apply baselines and clamp minimum to zero
  float heel  = max(0.0f, rawHeel  - baselines.heel);
  float inner = max(0.0f, rawInner - baselines.inner);
  float outer = max(0.0f, rawOuter - baselines.outer);
  float toe   = max(0.0f, rawToe   - baselines.toe);
  float piezo = max(0.0f, rawPiezo - baselines.piezo);

  lastHeel = heel;
  lastInner = inner;
  lastOuter = outer;
  lastToe = toe;
  lastPiezo = piezo;

  // Broadcast WebSocket JSON frame
  char jsonPayload[256];
  snprintf(
    jsonPayload,
    sizeof(jsonPayload),
    "{\"heel\":%.2f,\"inner\":%.2f,\"outer\":%.2f,\"toe\":%.2f,\"piezo\":%.2f,\"pitch\":%.2f,\"roll\":%.2f,\"accZ\":%.2f}",
    heel, inner, outer, toe, piezo, pitchDeg, rollDeg, accZ
  );
  wsServer.broadcastTXT(jsonPayload);

  // Output USB Serial CSV (Compatible with NIVA web serial parser)
  Serial.printf("%.2f,%.2f,%.2f,%.2f,%.2f,%.2f,%.2f,%.2f\n",
                heel, inner, outer, toe, piezo, pitchDeg, rollDeg, accZ);

  if (now - lastDisplayAt >= DISPLAY_INTERVAL_MS) {
    lastDisplayAt = now;
    showLiveReadout(WiFi.status() == WL_CONNECTED);
  }
}

// -----------------------------------------------------------------------------
// If the display stays blank
// -----------------------------------------------------------------------------
// 1. Try U8G2_SH1106_128X64_VCOMH0_F_HW_I2C instead of ...NONAME_F_HW_I2C
//    (same line, both declaration above and nowhere else needs to change).
// 2. If neither SH1106 variant works, your panel may actually be SSD1306:
//    U8G2_SSD1306_128X64_NONAME_F_HW_I2C u8g2(U8G2_R0, U8X8_PIN_NONE);
// 3. Re-run an I2C scanner sketch to confirm the address is still 0x3C —
//    some SSD1306/SH1106 boards ship at 0x3D instead.

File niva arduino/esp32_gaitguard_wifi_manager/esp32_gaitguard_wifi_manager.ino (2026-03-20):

#include <WiFi.h>
#include <WebSocketsServer.h>

// ------------------------------
// Hardware pin map
// ------------------------------
static const int PIN_HEEL = 32;
static const int PIN_INNER = 33;
static const int PIN_OUTER = 34;
static const int PIN_TOE = 35;
static const int PIN_PIEZO = 36;

// ------------------------------
// Stream and filter settings
// ------------------------------
static const unsigned long STREAM_INTERVAL_MS = 100;

// ------------------------------
// Zero-load calibration settings
// ------------------------------
static const uint16_t CALIBRATION_SAMPLES = 40;

// ------------------------------
// WiFi reconnect settings
// ------------------------------
static const unsigned long WIFI_CHECK_INTERVAL_MS = 3000;

// Hardcode your hotspot credentials here.
static const char* WIFI_SSID = "YOUR_HOTSPOT_NAME";
static const char* WIFI_PASS = "YOUR_HOTSPOT_PASSWORD";

WebSocketsServer wsServer(81);

struct ChannelState {
  float baseline = 0.0f;
};

ChannelState heelState;
ChannelState innerState;
ChannelState outerState;
ChannelState toeState;
ChannelState piezoState;

bool isCalibrated = false;
uint16_t calibrationCount = 0;
float calibrationHeel = 0.0f;
float calibrationInner = 0.0f;
float calibrationOuter = 0.0f;
float calibrationToe = 0.0f;
float calibrationPiezo = 0.0f;

unsigned long lastStreamAt = 0;
unsigned long lastWiFiCheckAt = 0;
 
float applyBaseline(float raw, const ChannelState& state) {
  float adjusted = raw - state.baseline;
  if (adjusted < 0.0f) adjusted = 0.0f;
  return adjusted;
}

void printWiFiStatus() {
  Serial.println("WiFi Connected");
  Serial.print("ESP32 IP: ");
  Serial.println(WiFi.localIP());
}

void connectHardcodedWiFi() {
  WiFi.mode(WIFI_STA);
  WiFi.setAutoReconnect(true);
  WiFi.begin(WIFI_SSID, WIFI_PASS);

  Serial.print("Connecting to WiFi");
  unsigned long startAt = millis();
  while (WiFi.status() != WL_CONNECTED && millis() - startAt < 20000) {
    delay(500);
    Serial.print(".");
  }
  Serial.println();

  if (WiFi.status() == WL_CONNECTED) {
    printWiFiStatus();
  } else {
    Serial.println("WiFi connect failed. Check WIFI_SSID/WIFI_PASS.");
  }
}

void maintainWiFi() {
  unsigned long now = millis();
  if (now - lastWiFiCheckAt < WIFI_CHECK_INTERVAL_MS) return;
  lastWiFiCheckAt = now;

  if (WiFi.status() != WL_CONNECTED) {
    Serial.println("WiFi lost. Attempting reconnect...");
    WiFi.disconnect(true);
    WiFi.begin(WIFI_SSID, WIFI_PASS);
  }
}

void setup() {
  Serial.begin(115200);
  delay(300);

  analogReadResolution(12);

  pinMode(PIN_HEEL, INPUT);
  pinMode(PIN_INNER, INPUT);
  pinMode(PIN_OUTER, INPUT);
  pinMode(PIN_TOE, INPUT);
  pinMode(PIN_PIEZO, INPUT);

  connectHardcodedWiFi();

  wsServer.begin();

  Serial.println("Calibrating FSR");
}

void loop() {
  maintainWiFi();
  wsServer.loop();

  unsigned long now = millis();
  if (now - lastStreamAt < STREAM_INTERVAL_MS) return;
  lastStreamAt = now;

  float rawHeel = static_cast<float>(analogRead(PIN_HEEL));
  float rawInner = static_cast<float>(analogRead(PIN_INNER));
  float rawOuter = static_cast<float>(analogRead(PIN_OUTER));
  float rawToe = static_cast<float>(analogRead(PIN_TOE));
  float rawPiezo = static_cast<float>(analogRead(PIN_PIEZO));

  if (!isCalibrated) {
    calibrationCount += 1;
    calibrationHeel += rawHeel;
    calibrationInner += rawInner;
    calibrationOuter += rawOuter;
    calibrationToe += rawToe;
    calibrationPiezo += rawPiezo;

    if (calibrationCount >= CALIBRATION_SAMPLES) {
      heelState.baseline = calibrationHeel / calibrationCount;
      innerState.baseline = calibrationInner / calibrationCount;
      outerState.baseline = calibrationOuter / calibrationCount;
      toeState.baseline = calibrationToe / calibrationCount;
      piezoState.baseline = calibrationPiezo / calibrationCount;

      isCalibrated = true;
      Serial.println("Calibration Done");
      Serial.println("SYSTEM READY");
    }

    // Keep stream alive during calibration with zeros.
    const char* calibratingPacket = "{\"heel\":0,\"inner\":0,\"outer\":0,\"toe\":0,\"piezo\":0,\"pitch\":0,\"roll\":0,\"accZ\":0}";
    wsServer.broadcastTXT(calibratingPacket);
    Serial.println("0,0,0,0,0,0,0,0");
    return;
  }

  float heel = applyBaseline(rawHeel, heelState);
  float inner = applyBaseline(rawInner, innerState);
  float outer = applyBaseline(rawOuter, outerState);
  float toe = applyBaseline(rawToe, toeState);
  float piezo = applyBaseline(rawPiezo, piezoState);

  const float pitchDeg = 0.0f;
  const float rollDeg = 0.0f;
  const float accZ = 0.0f;

  char jsonPayload[220];
  snprintf(
    jsonPayload,
    sizeof(jsonPayload),
    "{\"heel\":%.2f,\"inner\":%.2f,\"outer\":%.2f,\"toe\":%.2f,\"piezo\":%.2f,\"pitch\":%.2f,\"roll\":%.2f,\"accZ\":%.2f}",
    heel,
    inner,
    outer,
    toe,
    piezo,
    pitchDeg,
    rollDeg,
    accZ
  );

  wsServer.broadcastTXT(jsonPayload);

  // USB serial CSV output compatible with dashboard serial parser.
  Serial.printf(
    "%.2f,%.2f,%.2f,%.2f,%.2f,%.2f,%.2f,%.2f\n",
    heel,
    inner,
    outer,
    toe,
    piezo,
    pitchDeg,
    rollDeg,
    accZ
  );
}

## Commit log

2026-03-20 Add runtime ESP32 WiFi/hotspot endpoint configuration
2026-03-20 Enable seamless relay fallback for deployed ESP32 connectivity
2026-03-20 Add runtime relay endpoint input and stable relay routing
2026-03-20 Add default controls and low-noise zero-load calibration
2026-03-20 Simplify ESP32 hardcoded WiFi firmware
2026-07-22 Initial commit: GaitGuard Nexus Flutter app
    Scaffolded platform folders and fixed compile/runtime bugs found by
    actually running the app for the first time (heel-strike detection
    gated on smoothed rather than raw pressure, a lazily-built
    AnimationController crashing on dispose, an unhandled WebSocket
    connection exception, and a couple of import/typo compile errors).
    [main.cpp]
2026-07-22 Fix ESP32 connectivity and rework connect/reconnect UX
    Real-device connections were impossible: the Android manifest had no
    INTERNET permission or cleartext-traffic allowance, and iOS had no
    local-network/ATS exception, both needed for a plaintext ws:// link to
    the ESP32. Also replaces the flat 1.5s reconnect timer with capped
    exponential backoff + jitter, stops a single malformed frame from
    leaving a stale error banner, fixes live/simulation modes leaving each
    other's timers or sockets running in the background, and gives the
    Device screen real Connecting/Connected/Error states with a retry
    action and inline endpoint validation.
2026-07-22 Redesign plantar pressure map around real FSR reference diagram
    Replaces the procedurally-drawn single-foot outline with the actual
    feet.png diagram from the original web app, showing both feet with
    glowing pressure zones (toe, 1st MT, 5th MT, heel) driven by the live
    heel/inner/outer/toe sensor readings instead of a synthetic radial
    gradient. Zone positions were grid-calibrated against the asset in a
    companion Figma design pass. Also adds the "12-BIT ADC" badge next to
    the pressure map label, a real spec (the ESP32's ADC is 12-bit,
    matching the /4095 normalization already in biomechanics_engine.dart)
    rather than decorative text.
2026-07-22 Polish UI/UX, add AI Coach, verify simulation fidelity, fix app icon
    - Dark-mode vignette + disconnected caption on the pressure map, breathing
    idle pulse on health rings, cross-fade tab transitions, haptics across
    interactive controls, truncated anomaly list, first-run orientation card,
    and empty states for insights cards while disconnected
    - New template-based AI Coach chat on the Insights screen: keyword-matched
    answers driven by live biomechanics data, typewriter streaming, no network
    calls, swappable AiCoachService interface for a future real backend
    - Corrected simulation fidelity against BACKEND_LOGIC.md/SIMULATION_LOGIC.md:
    randomized (not deterministic) pitch/roll, 10Hz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
2026-08-17 Reorganize Niva into a flutter, arduino, and web monorepo.
    Keep the existing GitHub history and place each application in its own top-level folder, with the complete ESP32 firmware and WebSocket relay included.
2026-09-27 Add NIVA hardware work-in-progress (CAD, KiCad, blueprints, brief)
    [01_RearHousing.step, 01_RearHousing.stl, 02_FrontCover.step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]
2026-09-27 NIVA Rev C: connected KiCad 9 schematic hierarchy with ERC and exports
    Rev B schematics never parsed in KiCad (each placed symbol was left
    unclosed) and the official Espressif symbol library is KiCad 10 format.
    Rebuild as one hierarchy (root + controller + heel/indicator) with
    global power symbols and hierarchical sheet pins, down-convert the
    Espressif symbol for KiCad 9, and apply the electrical review:
    VEXC current limit and sensing, ID filtering, BAS416 piezo clamps,
    anti-alias retune, decoupling per device, spring-contact battery
    interface, KMR2 button. ERC: 0 errors, 1 reviewed warning.
    Claude-Session: https://claude.ai/code/sessi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
    [NIVA-controller.kicad_sch, NIVA-heel-and-indicator.kicad_sch, NIVA-pod-BOM.csv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]
2026-09-27 NIVA Rev C: KiCad placement prototype PCB and audited enclosure
    PCB: 4-layer 34x48 mm board generated from the netlist with pcbnew,
    official Espressif module footprint + STEP, KiCad library models,
    antenna keepout, In1 GND plane, corner notches around the enclosure
    bosses. Freerouting stalled at ~40 unrouted connections, so the board
    is delivered and labelled as an UNROUTED PLACEMENT PROTOTYPE.
    Enclosure: new niva_layout.py shared by PCB and FreeCAD generators;
    continuous gasket with boss hard stops, bossed cover screws, PCB bosses,
    ledges and clamp ribs, connector-height keyed tail aperture, light pipe
    to emitters, bay ceiling, spring-contact cartridge lid, cradle rails,
    latch and L/R keys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
    [01_RearHousing_L.step, 01_RearHousing_L.stl, 01_RearHousing_R.step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]
2026-09-27 NIVA Rev C: documentation, final exports, captioned PCB renders
    - ELECTRICAL-REVIEW.md, PRINT-AND-ASSEMBLY.md and package README
    - R33 raised to 220R (22R would dissipate 0.5 W in an 0603 on a tail short)
    - deterministic schematic UUIDs; generators accept only KiCad 9 libraries
    - regenerated ERC/netlist/BOM/PCB/DRC/PCBA STEP+GLB/assembly PDFs
    - Blender scene builder and caption tool; KiCad raytraced PCB views
    - stale Rev B generated outputs removed (kept in git history)
    Claude-Session: https://claude.ai/code/session_01HNzeJFE5uNHjapog53SHnm
    [01_RearHousing.step, 01_RearHousing.stl, 01_RearHousing_L.step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]
2026-09-27 NIVA Rev C: refresh PCB component meshes from final PCBA STEP
    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
    [PCB_Components_KiCad_L.stl, PCB_Components_KiCad_R.stl]
2026-09-27 NIVA Rev C: final PCB close-up render (raw)
    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
2026-09-27 NIVA Rev C: final captioned renders, Blender scenes and GLB exports
    - 5 Blender Cycles scenes (assembled, exploded, PCB, flat lay, bilateral
    kit) + 4 KiCad raytraces, each captioned with provenance and status
    - NIVA-RevC-scenes.blend (Blender 4.5) and one GLB per scene
    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
    [NIVA-RevC-scenes.blend]
2026-09-28 Add cartridge interconnect PCB, charging dock PCB and dock enclosure; ratiometric ADC reference
    - Pod schematic: MCP3208 VREF driven from VEXC (the sensor excitation rail) so every
    channel is ratiometric in hardware; CH6 reads +3V3/2 as a rail monitor.
    - Cartridge: 3.4 mm interconnect strip (cell leads, polyfuse, lid-plate leads, underside
    dock pads), hand-routed; ERC/DRC clean with schematic parity.
    - Dock: USB-C sink, MCP73831 charger gated by an LM393 NTC window comparator, spring
    pins to the cartridge pads; autorouted (Freerouting) and DRC clean.
    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
    [01_RearHousing_L.step, 01_RearHousing_L.stl, 01_RearHousing_R.step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]
2026-09-28 Route the pod PCB, add BAV199 clamp, insole sensing flex, verification plan
    - Pod: 0.15/0.127 mm rules; every GND pad fanned out to the In1 plane before
    autorouting, signals routed with Freerouting, GND pours stitched on all layers.
    KiCad DRC: 0 errors, 0 unconnected, schematic parity clean.
    - D2/D3 BAS416 singles replaced by one BAV199 series pair on a project symbol
    that states the datasheet pinning.
    - Insole flex (right/left medium): five interdigitated shunt-mode electrodes,
    PVDF bond pads, paired lanes to the heel tab, above-collar transition with the
    insert ID resistor; F.Cu only and no parts underfoot. ERC/DRC clean.
    - export_niva_electronics.py writes all board outputs; fab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
    [01_RearHousing_L.step, 01_RearHousing_R.step, 02_FrontCover_L.step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]
2026-09-28 Re-render all scenes for Rev C.1; add dock and insole-flex scenes
    - Seven Blender scenes re-rendered with the routed pod PCBA, the LP502030 cell
    and cartridge strip, and linearised KiCad GLB colours (the pale-mask fix);
    new 06_Dock_Charging and 07_Insole_Flex scenes and GLBs.
    - KiCad raytraces of the routed pod (render_kicad_pcb.sh); captions state the
    routed-but-unreviewed status and the remaining envelopes.
    - Root README entry updated; stale docstring path fixed; Blender .blend1
    backups ignored.
    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
    [NIVA-RevC-scenes.blend]
2026-09-28 Add SIH 2026 deck kit for kit-matched idea decks
    The HTML-to-PDF pipeline, the locked SIH 2026 template frame and the
    approved SURANG-SUTRA PS 26218 deck as a style reference. This lets a
    cloud session build the NIVA deck in the same template. Bundled OFL
    fonts keep the layout identical on Linux. PROMPT-NIVA.md holds the
    pre-filled session prompt.
2026-10-25 Pod PCB: PCBWay prototype Gerbers, 0.2 mm via drills
    Recheck the routed Rev C.1 pod board in KiCad 10.0.7 and export a
    bare-PCB first-article set for PCBWay's standard 4-layer process.
    - Via drill 0.25 -> 0.2 mm on all 126 vias (pad stays 0.5 mm), so the
    annular ring is 0.15 mm. Copper is unchanged; project rules match.
    - KiCad 10 ERC/DRC with default libraries and schematic parity:
    0 errors, 0 unconnected. Reports replaced.
    - fab-PROTOTYPE-PCBWAY/NIVA-pod: Gerbers (Protel names, no X2),
    separate PTH/NPTH drills, placement, upload zip, STATUS.txt with the
    blockers still open (J2 part, U6 package, antenna check, no review).
    - The pod's review-only set is removed; README and ELECTRICA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
2026-10-25 Pod PCB: add PCBWay text to bottom silkscreen
    PCBWay's Future Innovators Program requires the PCBWay name or logo
    on every supported board. Add "PCBWay" (1 mm, 0.15 mm stroke) on
    B.Silkscreen under "NIVA REV C", in a spot clear of pads, vias and
    other silk. Re-export the PCBWay Gerbers and zip; only the bottom
    silkscreen changes (copper and drill differ by timestamp only).
    KiCad 10.0.7 DRC with parity: 0 errors, 0 unconnected, same 13
    warnings as before.
2026-11-06 Pod PCB: JLCPCB prototype Gerbers (PCBWay silk text removed)
    Same copper, mask and drills as the PCBWay export; only B.Silkscreen
    differs. KiCad 10.0.7 DRC: 0 errors, 0 unconnected.

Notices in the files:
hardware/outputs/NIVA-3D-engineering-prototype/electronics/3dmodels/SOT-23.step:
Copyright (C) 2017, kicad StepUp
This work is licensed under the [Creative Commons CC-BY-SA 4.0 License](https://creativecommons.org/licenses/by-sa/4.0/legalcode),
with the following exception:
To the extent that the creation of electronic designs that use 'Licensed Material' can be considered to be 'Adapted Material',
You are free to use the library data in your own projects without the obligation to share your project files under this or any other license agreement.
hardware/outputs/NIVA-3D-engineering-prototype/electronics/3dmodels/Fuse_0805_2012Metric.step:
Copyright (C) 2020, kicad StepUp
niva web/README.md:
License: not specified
